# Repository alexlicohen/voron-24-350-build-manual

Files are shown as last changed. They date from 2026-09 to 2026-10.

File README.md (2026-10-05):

# Voron 2.4 R2 (LDO Rev D+, 350 mm) — build manual

**Live site:** <https://alexlicohen.github.io/voron-24-350-build-manual/> — one page per step, built from `docs/` on every push to `main`.

A Prusa-style, single-track build manual for an LDO Voron 2.4 R2 Rev D+ 350 kit, with every printed part produced on a Prusa Core One+. Numbered steps, fasteners per step, "what you should see" checks, and print batches interleaved with assembly so the printer never idles and no chapter waits on a part.

- `docs/manual/00-index.md` — start here: the interleaved print/build timeline, critical path, corrections log.
- `docs/manual/00-…14-*.md` — assembly chapters (frame → calibration), transcribed from the official Voron 2.4r2 manual with LDO Rev D/D+ deviations inline.
- `docs/manual/print/` — PrusaSlicer setup (quality-first overrides) and eleven print-batch chapters with per-plate packing lists.
- `docs/voron-print-plan.md`, `docs/voron-build-instructions-survey.md` — the research the chapters are built from.
- `slicer/` — the PrusaSlicer 2.9.6 config bundle and one committed project per plate.

The manual reads as **one page per step**, Prusa-style. `scripts/build_steps.py` runs as an mkdocs hook and regenerates `docs/manual/steps/` on every build — a chapter overview with a thumbnail grid, plus one page per `### Step NN.M` with prev/next, from the chapter markdown, which stays the single source. That directory is gitignored; the chapters are what you edit. Contract: [`docs/manual/CONVENTIONS.md` § Step pages](docs/manual/CONVENTIONS.md).

Optional bench tooling, not part of the manual: `scripts/ingest_photos.py` files a photo of a step from a drop folder (resize, EXIF strip) and `scripts/photo_wanted.py` lists steps with no illustration. Alex's 2026-09-06 ruling is that this is a manual to build from, not a record — the manual asks for no photos, and neither script is needed to build or read it.

## Slicer projects

`slicer/` holds a PrusaSlicer **2.9.6** project for each of the 22 plates (`slicer/plates/B01-P1.3mf`, 30 MB total), each one carrying its own arrangement on the 250 × 220 bed, its per-object brims and the complete print/filament/printer configuration — open one with **File → Open Project** and slice, without re-entering the thirty-odd Voron overrides by hand or guessing at a plate layout. The configuration is generated, not hand-written: `slicer/build_config.py` reads the system presets (`0.20mm STRUCTURAL @COREONE 0.4`, `Prusament ASA @COREONE HF0.4`, `Prusa CORE One HF0.4 nozzle`) out of the `PrusaResearch.ini` shipped with the installed slicer, resolves `inherits`, applies the override table from `docs/manual/print/00-slicer-setup.md`, and writes `slicer/OVERRIDES.md` mapping every key back to the doc line it came from. Every hour and gram quoted in the print plan and the batch chapters is read from the G-code these projects produce (`slicer/estimates.csv`), which is why they replaced the throughput model that preceded them: **157.0 h / 2092 g**, against the model's 134.3 h / 2248 g. Rebuild the lot with `python3 slicer/fetch_stls.py && python3 slicer/build_plates.py` — the STLs themselves are not committed (78 MB, re-fetchable from the commits pinned in `slicer/stl/MANIFEST.sha256`).

## Read it

```bash
python3 -m venv .venv && .venv/bin/pip install -r requirements.txt
./scripts/serve.sh        # prints the LAN URL; open it on a tablet at the bench
```

The rendered manual pages under `docs/manual/assets/manual-pages/` come from the official manual PDF, which is not committed (size). To regenerate:

```bash
curl -L -o docs/manual/assets/Voron2.4r2-manual.pdf \
  https://raw.githubusercontent.com/VoronDesign/Voron-2/de7e89d/Manual/Assembly_Manual_2.4r2.pdf
pdftoppm -png -r 110 docs/manual/assets/Voron2.4r2-manual.pdf docs/manual/assets/manual-pages/manual-p
```

The rendered Stealthburner manual pages under `docs/manual/assets/sb-pages/` come from the official Stealthburner manual PDF, also not committed (size). To regenerate:

```bash
curl -L -o docs/manual/assets/Voron-Stealthburner-manual.pdf \
  https://raw.githubusercontent.com/VoronDesign/Voron-Stealthburner/1bccf0543f40741243d81505c4ad5406eb822715/Manual/Assembly_Manual_SB.pdf
pdftoppm -png -r 110 docs/manual/assets/Voron-Stealthburner-manual.pdf docs/manual/assets/sb-pages/sb-p
# the SB manual has <100 pages, so pdftoppm 2-digit-pads by default — rename to the 3-digit sb-pNNN.png the chapters reference
cd docs/manual/assets/sb-pages && for f in sb-p-*.png; do n=$(echo "$f" | sed -E 's/sb-p-0*([0-9]+)\.png/\1/'); mv "$f" "$(printf sb-p%03d.png "$n")"; done && cd -
```

## Sources and drift

Every external URL cited in `docs/**/*.md` is inventoried in [`sources.yml`](sources.yml) — one row per source, with a title, a `kind`, and (for GitHub sources) the commit SHA of the default branch at the time it was last checked. Rebuild the inventory with `python3 scripts/sources_build.py`; re-check it with `python3 scripts/sources_verify.py --dry-run` (add no flag to also refresh `last_verified`/`sha` in place).

[`.github/workflows/drift.yml`](.github/workflows/drift.yml) runs weekly against the git repos this manual is most exposed to (`Voron-2`, `Voron-Documentation`, LDO's `Nitehawk-SB-V2` and `LDOVoron2`, `Voron-Stealthburner`, PrusaSlicer's settings repo) and opens or updates a single "Upstream drift" issue when any of them moves or a pinned URL stops resolving. It does not diff `docs.ldomotors.com` — that site is JS-rendered and would be all noise; LDO drift still surfaces through the corrections log and manual URL checks.

## Contributing

Found a step that doesn't match your kit? See [`CONTRIBUTING.md`](CONTRIBUTING.md) — corrections and questions both have issue templates, and PRs run through the same `mkdocs build --strict` + `scripts/lint_manual.py` checks as `main`.

## CI and deploy

`.github/workflows/check.yml` runs on every PR: `mkdocs build --strict` (with `validation.links.anchors: warn`, so a broken cross-reference anchor now fails the build, not just a missing file), the `hooks/callouts.py` self-test, and `scripts/lint_manual.py` (truncated callouts, dangling `Step NN.M` references, STLs printed in no batch, tables over 7 columns, and the per-step word budgets from `docs/manual/CONVENTIONS.md`). `.github/workflows/deploy.yml` runs on push to `main`: same strict build, then `mkdocs gh-deploy --force` — chosen over `actions/deploy-pages` because `gh-pages` already exists as a classic branch-based Pages source and this keeps that config unchanged.

## Attribution and licences

- Voron 2.4r2 assembly manual pages (rendered PNGs) and Stealthburner/gantry-squaring images: © VoronDesign, [GPL-3.0](https://github.com/VoronDesign/Voron-2/blob/Voron2.4/LICENSE). Page images are reproduced under that licence; the pinned source commit is `de7e89d`.
- Voron Stealthburner assembly manual pages (rendered PNGs, `docs/manual/assets/sb-pages/`): © VoronDesign, [GPL-3.0](https://github.com/VoronDesign/Voron-Stealthburner/blob/main/LICENSE). Reproduced under that licence; the pinned source commit is `1bccf054`.
- LDO Motors documentation images (docs.ldomotors.com) and MotorDynamicsLab repository images (LDOVoron2, Leviathan, Nitehawk-SB-V2) are reproduced with attribution for this non-commercial build manual; each mirrored file is listed in the folder's `SOURCES.txt` with its original URL. © LDO Motors. If LDO objects, open an issue and the images will be replaced with links.
- Per-part renders (`docs/manual/assets/parts/`), explanatory diagrams (`docs/manual/assets/diagrams/`) and CAD-derived step views (`docs/manual/assets/cad/`, from the GPL-3.0 Voron 2.4r2 STEP assembly at commit `de7e89d`) are generated by scripts in `scripts/`; regenerate with `python scripts/render_parts.py`, `python scripts/draw_diagrams.py`, and the pipeline described in `docs/manual/assets/cad/PILOT.md`.
- Klipper documentation excerpts are GPL-3.0.
- Everything else in this repository (chapter text, print plan, survey) is provided as-is for personal builds; no warranty. Steps marked `(verify on bench)` are counts or details no source states — confirm on your own kit.
- This repository's own content (chapter text, print plan, survey, diagrams, renders, scripts and the bench and add-on designs it generates) is licensed [CC BY-NC-SA 4.0](https://creativecommons.org/licenses/by-nc-sa/4.0/) (`LICENSE`). Third-party material listed above keeps its own licence: GPL-3.0 stays GPL-3.0 (Voron, Stealthburner, Klipper, the B11 duct remixes in `slicer/stl/bayducts/`, the Clicky-Clack images), and LDO's images remain © LDO Motors.
- `docs/manual/assets/` intentionally keeps the full rendered page range from each source PDF, including pages no chapter currently cites — that's deliberate (chapters are still being filled in against page references), not an oversight.

This manual is for one specific kit revision. If your kit differs (Rev C/D, different toolboard, different probe), the corrections log in the index tells you which steps to re-check.

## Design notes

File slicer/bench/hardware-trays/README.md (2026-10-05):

# Hardware trays (bench print)

Three ultra-light Gridfinity bins on one common footprint (5 × 5 units), each only as tall as its contents
need, that hold the LDO Voron 2.4 350 kit's fastener bags: one
compartment per hardware row of the kit BOM, two raised label lines (size; type and kit count) on a ledge
behind each row, and a scoop cove along each compartment's front wall. They sit on any Gridfinity baseplate
(Clickfinity included), and any of them stacks on any other. The bags are emptied into them on kit day,
[Ch 00 Step 00.12](../../../docs/manual/00-before-you-start.md#step-0012-empty-the-fastener-bags-into-the-hardware-trays).
A bench print: on no plate, in no batch, run total or spool ledger
([print/README § Bench prints](../../../docs/manual/print/README.md#bench-prints-outside-the-plates)).

| Tray | Holds |
|---|---|
| A | M2 and M3 screws: SHCS by length, BHCS, FHCS, wafer, captive, M2 self-tappers, M3 set screws |
| B | M4 and M5 screws (M5 SHCS, M4 and M5 BHCS, M4 set screws) and the hammer-head T-nuts |
| C | the small parts (hex nuts, heat-set inserts, washers, spacers, lock washers, knurled nuts, magnets) and the roll-in T-nuts, in a low bin |

The kit's hand tools (hex keys, the 2 mm drill bit, the slot screwdriver, the brass insert tip) are not
stored in the trays. Renders (blue = the layers above the label ledges, i.e. the colour-change layers):
`renders/tray-{A,B,C}-top.png` and `renders/tray-{A,B,C}-34.png`.

## Files

| File | What |
|---|---|
| `gen_trays.py` | the only generator (CadQuery, `venv-cq`; no other dependency) |
| `tray-{A,B,C}.stl` | print-ready meshes, as oriented |
| `tray-{A,B,C}.3mf` | PrusaSlicer 2.9.6 projects, one tray per bed, config embedded |
| `renders/*.png` | top and 3/4 views of each tray, and a Y–Z section (`-section.png`) |

## Regenerate

```sh
venv-cq/bin/python slicer/bench/hardware-trays/gen_trays.py            # STLs, renders, 3MFs, slice, README blocks
venv-cq/bin/python slicer/bench/hardware-trays/gen_trays.py --plan     # groupings and fill table only, writes nothing
venv-cq/bin/python slicer/bench/hardware-trays/gen_trays.py --compare 3  # build and slice the 3 best groupings, print h and g
venv-cq/bin/python slicer/bench/hardware-trays/gen_trays.py --lever-study  # slice with the plastic levers added one by one
venv-cq/bin/python slicer/bench/hardware-trays/gen_trays.py --levers none  # the plain (solid-base, 2.6 mm wall) bins
venv-cq/bin/python slicer/bench/hardware-trays/gen_trays.py --no-slice
venv-cq/bin/python slicer/bench/hardware-trays/gen_trays.py --holes magnet   # or screw; default none
venv-cq/bin/python slicer/bench/hardware-trays/gen_trays.py --validate REF.stl   # profile check, below
```

Everything is read from the data: the rows of box *Fasteners, Tools & Misc* in `scripts/data/ldo-350-bom.yml`
(re-pinned to the batch sheet on kit day, Step 00.2) and the `tool` roles in
`scripts/data/hardware-ownership.yml`. Re-run after a re-pin; the grid, the split, the compartment sizes and
the labels follow the counts. The script stops on a BOM row it has no rule for (`classify()`), on any
compartment over 70 % fill or under the finger floor, on a slicer stability warning, and if no split fits
six trays. The STLs and renders are byte-identical between runs. About 5 minutes.

Not in a compartment: the PTFE tube, the zip ties, the two aluminium handles and the hand tools. The Motion
box's loose parts (F695 and 625 bearings, pulleys, GT2 idlers, 5×60 shafts, the nozzle-probe shaft, MR85s,
the IDGA gear set, the Bowden coupler) stay sealed in their own kit bags: they are sealed precision parts
that only pick up grit in an open tray, each bag already holds one part type with its name on it, and they
are opened at a few known drive and toolhead steps, not drawn on every session like the screws.

## Fill check

Every compartment is sized so its loose contents fill at most **70 %** of its usable volume, leaving room to
scoop, and the script fails if one does not. Per hardware row:

- **Envelope:** the bounding shape of one piece: a cylinder of the head diameter over the overall length
  for screws (head height + length; length only for FHCS), a cylinder across the corners for hex nuts,
  diameter × thickness for washers, spacers, inserts and magnets, a box for T-nuts. Shank diameter is the
  nominal thread.
- **Bulk volume** = count × envelope ÷ φ, the random-loose packing fraction of that envelope:
  - screws: 0.55 at envelope length/diameter ≤ 2 down to 0.45 at ≥ 8, linear between. Random packings of
    cylinders loosen as they get longer, and the bounding cylinder already pads the shank out to the head
    diameter.
  - set screws, inserts, washers, spacers, T-nuts: 0.55 (short, blocky or flat pieces that interlock or
    shingle).
  - hex nuts, knurled nuts: 0.58; magnets: 0.60 (they chain and stack).
- **Usable volume** = compartment floor area × depth from the floor to the rim (the divider tops), less the
  rounded vertical corners (R2.9), the scoop cove (always R12: compartments are at least 18 mm long and 21 mm deep, so it never shrinks), and
  on a side against the outer wall the 1.74 × 1.74 mm 45° sliver of the lip support.
- **Fill** = bulk ÷ usable. Compartments are sized from the 70 % rule, with a floor of 25 mm wide × 18 mm long
  so a finger fits, and wider where the label (or a screw lying along X) needs it; spare space is shared out
  in proportion.

Sources for the piece dimensions (column *source* in the generated table):

- ISO 4762 / 7380 / 10642 / 4032 / 7089 / 14583 / 4026: the dimension tables in
  [gumyr/bd_warehouse @eed2da1](https://github.com/gumyr/bd_warehouse/tree/eed2da118da99007ad2d3904466ac0b24964f84d/src/bd_warehouse/data)
  (`socket_head_cap_`, `button_head_`, `countersunk_head_`, `hex_nut_`, `plain_washer_`, `pan_head_parameters.csv`).
  Maxima where the table gives them (SHCS M3 head 5.68, not the nominal 5.5), so the envelopes err large.
- CAD: bounding boxes in the Voron 2.4r2 assembly STEP (VoronDesign/Voron-2) of the part the Voron design
  itself models for that BOM line: the roll-in T-nuts ("2020 Drop-in T-nut", 12.5–13.0 × 7.7 × 4.3), the M3
  hammer-head (10.92 × 9.14 × 4.85), the M5 1 mm shim (10 × 1), the insert's knurl (5.35), the DIN 466-B
  knurled nut (14.08 × 8), the magnet, the M2×10 self-tapper (4.0 × 11.6).
- NAME: the size in the LDO BOM text (M3x5x4 insert, 6x3 magnet, the 1 mm washer).
- EST, no drawing found: the M3×25 wafer head (Ø8 × 1.5), the M3×6 captive screw (as an ISO 4762 head),
  the M5 hammer-head T-nut (as the M3 one, 11 × 9.2 × 5), the twisted M5 split lock washer (9.2 × 2.4).

**Validation of the packing method: none.** No published loose-bulk figure for small screws was found (a
search for loose bulk density of M3 screws or small fasteners turned up only solid density and per-piece
masses), so the φ values are judgement within the brief's ranges, not measured. The implied solid fraction
of the loose pile (count × solid volume ÷ bulk, column *solid/bulk* below) runs from about 0.1 for long
screws to about 0.5 for washers; loose screws in a tray likely lie flatter than that, so the method errs
roomy for long screws. Kit day is the cheap calibration: tip the 283 M3×8 into their compartment and read the
fill against the table.

## Gridfinity

Implemented in CadQuery from the published spec, no Gridfinity library:
[gridfinity.xyz/specification](https://gridfinity.xyz/specification/) ("Gridfinity Design Reference v5",
willtree8) and the constants in
[kennetek/gridfinity-rebuilt-openscad `src/core/standard.scad` @910e22d](https://github.com/kennetek/gridfinity-rebuilt-openscad/blob/910e22d8607fd7f5f51ad5e5cbc5287a76810bfd/src/core/standard.scad).

| Feature | Value used |
|---|---|
| Grid | 42 mm pitch; bin outer 42 n − 0.5 (5 units: 209.5 mm); corner radius 3.75 (Ø7.5) |
| Base, per unit | from the bottom: 0.8 at 45°, 1.8 vertical, 2.15 at 45° (4.75 high); bottom 35.6 square r0.8, top 41.5 r3.75 |
| Height | 7 mm units; bin height 7 u includes the 7 mm base (profile + bridge) and excludes the lip (6U = 42 mm) |
| Stacking lip | from its inner tip at the bin height: 0.7 at 45°, 1.8 vertical, 1.9 at 45° (2.6 deep, 4.4 high) |
| Interior | floor at 5.8 (a floor plate on top of hollow feet, below); dividers and labels stop 1.2 below the bin height (rebuilt's lip support height), so a bin stacked on top never touches them |
| Holes (option) | magnet Ø6.5 × 2.4, or M3 Ø3 × 6, 8 mm in from each side of every unit; none by default (Clickfinity baseplates hold bins without magnets) |

Deliberate differences: the lip's knife-edge top is cut back to a 0.3 mm flat, so the bin is 0.3 mm under
the spec's height (rebuilt rounds the same edge with r0.6 instead); the inside is ultra-light (§ Ultra-light
below). The outside, feet and lip included, is unchanged, and the validation below is of these bins.

**Validation** (`--validate`, section through the unit centre, a plain 1 × 1 × 6U bin from this script
against a reference STL, both centred and bottom-aligned):

| Reference | Base outside | Wall outside | Lip inside |
|---|---|---|---|
| Gridfinity Refined, `Bin Handle w Lip.stl` ([Printables 413761](https://www.printables.com/model/413761), CC BY-SA) | 0.012 mm | 0.000 mm | 0.012 mm |
| Gridfinity Lite, `gridfinity-lite-1x1x6.stl` ([Printables 265271](https://www.printables.com/model/265271), CC BY) | 0.250 mm | 0.001 mm | 0.250 mm |

The Refined bin matches the spec to the mesh tolerance. The Lite bin's base and lip are both 0.25 mm per
side inside the spec numbers everywhere (bottom 35.2, not 35.6; lip 2.85 deep, not 2.6): a uniform offset,
the 0.25 clearance an older gridfinity-rebuilt applied to the profile itself. Either fits a standard
baseplate; these trays follow the current spec numbers.

## Print

Core One+, satin sheet (the PLA sheet, per `docs/manual/print/00-slicer-setup.md` § Print sheet), any PLA, door open. Each project carries its config, flattened from the
PrusaSlicer 2.9.6 system presets `0.20mm BALANCED @COREONE HF0.4` + `Prusament PLA @COREONE HF0.4` +
`Prusa CORE One HF0.4 nozzle` (`slicer/resolve_preset.py`), with this repo's printer-wide lines: the vendored
cold start (`slicer/coreone-cold-start.gcode`) and `M106 P3 S160` / `M106 P3 R` in the filament start/end
G-code (AFS bypass flaps, as `slicer/bay-ducts-petg.ini` does for PETG). Supports off. Ultra-light settings:
2 perimeters, 3 top and 3 bottom layers (minimum-thickness rules off, so it is 3 layers), 10 % infill; nothing
else is overridden (0.2 mm layers, 0.45 mm lines). The base's 45° steps print without support.

**Two-colour labels (optional):** the labels, the top 0.6 mm of the dividers and the stacking lip are
everything above the label ledges. In PrusaSlicer's layer slider, add a colour change (M600) at the tray's
*colour change Z* in the slice table below (the first layer above the ledges), then load the label colour
when the printer asks.

**No lids.** A bin stacked on a tray of the same footprint closes it (its base sits in the stacking lip), and
the bins sit on any Gridfinity baseplate. Which trays stack, and which fit the optional closed carry box,
[Gridfinity 5×4 rugged case, Voron Edition](https://www.printables.com/model/857097) (Akio, CC BY-NC-SA; a
5 × 4 grid of 6U bins), is worked out in the generated block below.

**Grouping.** The generator groups whole hardware families (M2/M3 screws, M4/M5 screws, roll-in T-nuts,
hammer-head T-nuts, small parts) into at most three trays on one common footprint, each tray at its lowest
height: fewest trays, then the fewest bin units (Σ n·m·U, a plastic proxy); groupings that tie on bin units
are sliced and the lightest wins. No tray is lower than **`MIN_U` = 4** (Alex: parts must not spill when a
tray tilts), and every piece lying flat stays at least 2 mm below the rim. Only 5 × 5 holds the M2/M3 screws,
so 5 × 5 is the common footprint. With `MIN_U` = 4 the best three groupings, all sliced (`--compare 3`,
ultra-light, 2026-10-05):

| Grouping (A / B / C) | Bin units | Time | PLA |
|---|---:|---|---:|
| M2/M3 6U / M4/M5 + hammer-head T-nuts 5U / roll-in T-nuts + small parts 4U (**built**) | 375 | 18.6 h | 652 g |
| M2/M3 6U / M4/M5 5U / all T-nuts + small parts 4U | 375 | 18.9 h | 663 g |
| M2/M3 6U / M4/M5 + roll-in T-nuts 6U / hammer-head T-nuts + small parts 4U | 400 | 19.2 h | 676 g |

The 4U floor costs 16 g and 0.4 h against the 3U small-parts tray it replaces (636 g, 18.2 h). The extra depth
moves nothing: the first two tie on bin units, so the slice decides, and the grouping already built is the
lighter by 11 g. Putting all the T-nuts with the M4/M5 screws still does not fit a 6U bin.

Every compartment has the full R12 scoop cove on its front wall, solid. `renders/tray-{A,B,C}-section.png`
are Y–Z sections through each tray at a third of its width, drawn from the STL, showing the coves, the label
ledges, the hollow feet and the lip.

## Ultra-light

Ideas from **HuMa**, *Gridfinity Ultra Light Bins* ([Printables 627719](https://www.printables.com/model/627719),
CC BY-NC-SA: 37 % less filament than a standard bin, a 3 × 4 × 6 bin 62 g instead of 98 g at 2 walls, 3 top
and bottom layers, 10 % infill). Ideas only; no geometry is used. Each lever, sliced with the others before it
(`--lever-study`, 2026-10-05, before `MIN_U` = 4 and the fixed R12 cove; grouping and heights re-chosen at
each step):

| Lever | A | B | C | All | Change | Kept |
|---|---:|---:|---:|---:|---:|---|
| none (the bins as approved: solid 7 mm base, 2.6 mm wall, 1.8 mm dividers) | 359 g 6U | 329 g 6U | 227 g 3U | 915 g, 23.8 h | | |
| `settings`: 2 perimeters, 3 top / 3 bottom, 10 % infill | 306 | 278 | 187 | 771 g, 20.3 h | −144 g | yes |
| `thin`: outer wall and dividers 0.86 mm (exactly 2 perimeters); lip on a 45° support | 271 | 214 (5U) | 207 (4U) | 692 g, 18.8 h | −79 g | yes |
| `ledges`: hollow under each label ledge, 45° roof | 269 | 219 | 219 | 707 g, 20.2 h | +15 g | **no** |
| `coves`: hollow inside each scoop cove, 45° roof | 274 | 225 | 225 | 724 g, 20.9 h | +17 g | **no** |
| `base`: hollow feet under a floor plate (with the two above still on) | 259 | 212 | 184 (3U) | 655 g, 19.8 h | −69 g | yes |
| **built**: `settings` + `thin` + `base` | 262 | 207 | 167 | **636 g, 18.2 h** | **−279 g (−30 %)** | |

- **Settings** pays most: the trays are almost all wall, so cutting top layers and infill takes plastic off
  every floor and ledge. All three trays slice with **0 gap-fill extrusions**.
- **Thin walls**: a 0.45 mm line at 0.2 mm layers spaces at 0.407, so two perimeters make a 0.86 mm wall
  with nothing between them. With a wall thinner than the 2.6 mm lip, the lip's inner tip sits on a 45° ring
  (from the wall face 1.74 mm below the rim up to the tip line at the rim, then straight up to the bin
  height): the same support gridfinity-rebuilt uses, and the load path for a stacked bin. The lip itself
  is left as the spec draws it: its 6.8 mm² section is at most ~5 g a tray, and it carries the stack. The
  tray name on the front face is dropped: a cut into a 0.86 mm wall leaves less than two perimeters.
- **Hollow ledges and coves cost plastic.** At 10 % infill a void inside a 13 mm ledge or a cove adds two
  perimeters round it on every layer, more than the sparse infill it replaces, and more print time. Both are
  implemented (`--levers settings,thin,ledges,coves,base`) and off.
- **Hollow base**: each foot is a shell, 0.86 mm walls following the foot profile and a 3-layer (0.6 mm)
  pocket floor, closed on top by a 1.05 mm floor plate at the base top (z 4.75–5.8); the compartment floor
  is flat at 5.8, 1.2 mm lower than before. The call: a **flat floor over closed feet**, not floors dipping
  into the feet as HuMa's bins do. Dipped floors would leave a 5 mm ridge every 42 mm across every
  compartment, wells with 45° sides where washers, magnets and set screws collect, and V-notches where a
  divider crosses a well; the coves would hang over the wells. The flat floor costs a 40 mm bridge over
  each foot pocket (PrusaSlicer's stability check lists it with the base grooves as "Long bridging
  extrusions"; no supports) and some of the plastic dipping would save. No tray drops a height unit from
  the lower floor alone: A still needs 6U, and `MIN_U` keeps C at 4U. Holes (`--holes`) need
  solid feet, so the option turns the hollow base off.

**Strength.** Tray A full is about 0.5 kg of steel.
- *Lifted by one end*: the tray is a box 209.5 × 209.5 × 42 mm with 0.86 mm walls. Every 25–80 mm a 0.86 mm
  divider is fused to the outer wall, and every row ends in a solid 13.2 mm label ledge running wall to wall
  (ribs). The floor is a 1.05 mm plate on 25 foot shells. The worst case, held at one edge with the steel
  spread evenly, puts about 0.5 N·m of bending on that section: well under 1 MPa in PLA, which yields near
  50 MPa. The lip is solid, so it is a sound place to grip.
- *Two full trays stacked*: about 5 N rests on the lower tray's lip ring, about 820 mm long, carried by the
  45° support into the walls: a few kPa.
- *Floor*: a 1.05 mm plate spans each 40 mm foot pocket, edges fixed, carrying a fraction of a newton per pocket.
- Every wall and divider is at least 2 perimeters, the floors at least 3 layers. Nothing here is close to
  a limit; the limit in use is a drop, not a load.

<!-- BEGIN generated:layout -->
Generated from `scripts/data/ldo-350-bom.yml` (box *Fasteners, Tools & Misc*, fetched 2026-09-24). Each tray is sized on its own: the smallest footprint, then the lowest height, that holds its group at ≤ 70% fill with the finger floor.

3 groupings of whole families fit ≤ 3 trays on one common footprint, each tray at its lowest height. Best five by bin units (Σ n·m·U, the plastic proxy):

1. 3 trays, 375 bin units: M2/M3 screws 5×5×6U | M4/M5 screws 5×5×5U | roll-in T-nuts + hammer-head T-nuts + small parts 5×5×4U
2. 3 trays, 375 bin units: M2/M3 screws 5×5×6U | M4/M5 screws + hammer-head T-nuts 5×5×5U | roll-in T-nuts + small parts 5×5×4U ← chosen
3. 3 trays, 400 bin units: M2/M3 screws 5×5×6U | M4/M5 screws + roll-in T-nuts 5×5×6U | hammer-head T-nuts + small parts 5×5×4U

2 groupings tie at 375 bin units; sliced: 1. 663 g, 18.9 h; 2. 652 g, 18.6 h. Chosen: 2, the lightest.

Usable depth (floor to rim) by height: 4U 21.0 mm, 5U 28.0 mm, 6U 35.0 mm.

| tray | bin | thickest piece lying flat (mm) | lowest height the fill allows |
|---|---|---:|---|
| A | 5 × 5 × 6U | 8 | 6U |
| B | 5 × 5 × 5U | 9.5 | 5U |
| C | 5 × 5 × 4U | 8 | 4U |

Stacking: a bin rests on another bin's stacking lip only if both have the same footprint (the lip runs round the rim, so a smaller bin's feet would drop inside). A, B and C share a footprint: any of them stacks on any other.
None of the trays fits the 5 × 4 rugged case.

**Tray A — M2 · M3 SCREWS:** Gridfinity 5 × 5 × 6U (209.5 × 209.5 × 42 mm + lip), 17 compartments in 4 rows (row 1 is the front); fullest M3×40 SHCS at 67%.

| row | label | count | piece envelope mm | φ | bulk cm³ | size mm | usable cm³ | fill |
|---:|---|---:|---|---:|---:|---|---:|---:|
| 1 | M3×8 · SHCS 283 | 283 | cyl 5.68 × 11 | 0.55 | 143.4 | 109 × 59 × 35.0 | 221.2 | 65% |
| 1 | M3×12 · SHCS 50 | 50 | cyl 5.68 × 15 | 0.54 | 35.2 | 31 × 59 × 35.0 | 62.9 | 56% |
| 1 | M3×16 · SHCS 30 | 30 | cyl 5.68 × 19 | 0.53 | 27.4 | 31 × 59 × 35.0 | 63.4 | 43% |
| 1 | M3×20 · SHCS 40 | 40 | cyl 5.68 × 23 | 0.52 | 45.2 | 34 × 59 × 35.0 | 69.6 | 65% |
| 2 | M3×25 · SHCS 12 | 12 | cyl 5.68 × 28 | 0.50 | 17.0 | 38 × 29 × 35.0 | 36.8 | 46% |
| 2 | M3×30 · SHCS 44 | 44 | cyl 5.68 × 33 | 0.49 | 75.6 | 119 × 29 × 35.0 | 115.4 | 66% |
| 2 | M3×35 · SHCS 6 | 6 | cyl 5.68 × 38 | 0.47 | 12.2 | 49 × 29 × 35.0 | 47.2 | 26% |
| 3 | M3×40 · SHCS 34 | 34 | cyl 5.68 × 43 | 0.46 | 81.0 | 78 × 45 × 35.0 | 120.8 | 67% |
| 3 | M3×50 · SHCS 4 | 4 | cyl 5.68 × 53 | 0.45 | 11.9 | 62 × 45 × 35.0 | 95.7 | 12% |
| 3 | M3×6 · BHCS 14 | 14 | cyl 5.7 × 7.65 | 0.55 | 5.0 | 30 × 45 × 35.0 | 46.3 | 11% |
| 3 | M3×25 · BHCS 6 | 6 | cyl 5.7 × 26.65 | 0.51 | 8.1 | 36 × 45 × 35.0 | 55.6 | 15% |
| 4 | M3×6 · FHCS 42 | 42 | cyl 6 × 6 | 0.55 | 13.0 | 32 × 20 × 35.0 | 20.9 | 62% |
| 4 | M3×10 · FHCS 8 | 8 | cyl 6 × 10 | 0.55 | 4.1 | 31 × 20 × 35.0 | 20.4 | 20% |
| 4 | M3×25 · WAFER 3 | 3 | cyl 8 × 26.5 | 0.53 | 7.6 | 35 × 20 × 35.0 | 22.9 | 33% |
| 4 | M3×6 · CAPTIVE 2 | 2 | cyl 5.68 × 9 | 0.55 | 0.8 | 36 × 20 × 35.0 | 24.0 | 3% |
| 4 | M2×10 · SELF-TAP 43 | 43 | cyl 4 × 11.6 | 0.54 | 11.7 | 42 × 20 × 35.0 | 27.9 | 42% |
| 4 | M3×2 · SET 5 | 5 | cyl 3 × 2 | 0.55 | 0.1 | 28 × 20 × 35.0 | 18.8 | 1% |

**Tray B — M4 · M5 SCREWS · T-NUTS:** Gridfinity 5 × 5 × 5U (209.5 × 209.5 × 35 mm + lip), 10 compartments in 3 rows (row 1 is the front); fullest M5×40 SHCS at 69%.

| row | label | count | piece envelope mm | φ | bulk cm³ | size mm | usable cm³ | fill |
|---:|---|---:|---|---:|---:|---|---:|---:|
| 1 | M5×40 · SHCS 26 | 26 | cyl 8.72 × 45 | 0.50 | 140.5 | 154 × 48 × 28.0 | 203.3 | 69% |
| 1 | M4×6 · BHCS 8 | 8 | cyl 7.6 × 8.2 | 0.55 | 5.4 | 25 × 48 × 28.0 | 33.4 | 16% |
| 1 | M5×6 · BHCS 1 | 1 | cyl 9.5 × 8.75 | 0.55 | 1.1 | 27 × 48 × 28.0 | 35.7 | 3% |
| 2 | M5×10 · BHCS 54 | 54 | cyl 9.5 × 12.75 | 0.55 | 88.7 | 51 × 92 × 28.0 | 128.7 | 69% |
| 2 | M5×14 · BHCS 4 | 4 | cyl 9.5 × 16.75 | 0.55 | 8.6 | 29 × 92 × 28.0 | 74.6 | 12% |
| 2 | M5×16 · BHCS 43 | 43 | cyl 9.5 × 18.75 | 0.55 | 103.9 | 59 × 92 × 28.0 | 150.9 | 69% |
| 2 | M5×30 · BHCS 26 | 26 | cyl 9.5 × 32.75 | 0.53 | 114.8 | 66 × 92 × 28.0 | 166.5 | 69% |
| 3 | M4×4 · SET 32 | 32 | cyl 4 × 4 | 0.55 | 2.9 | 27 × 26 × 28.0 | 18.7 | 16% |
| 3 | M3 T-NUT · HAMMER 75 | 75 | box 10.92 × 9.14 × 4.85 | 0.55 | 66.0 | 137 × 26 × 28.0 | 95.5 | 69% |
| 3 | M5 T-NUT · HAMMER 16 | 16 | box 11 × 9.2 × 5 | 0.55 | 14.7 | 42 × 26 × 28.0 | 28.9 | 51% |

**Tray C — NUTS · INSERTS · WASHERS · MAGNETS · T-NUTS:** Gridfinity 5 × 5 × 4U (209.5 × 209.5 × 28 mm + lip), 11 compartments in 3 rows (row 1 is the front); fullest M3 INSERT HEAT-SET at 58%.

| row | label | count | piece envelope mm | φ | bulk cm³ | size mm | usable cm³ | fill |
|---:|---|---:|---|---:|---:|---|---:|---:|
| 1 | M3 NUT · HEX 14 | 14 | cyl 6.35 × 2.4 | 0.58 | 1.8 | 41 × 35 × 21.0 | 29.0 | 6% |
| 1 | M5 NUT · HEX 30 | 30 | cyl 9.24 × 4.7 | 0.58 | 16.3 | 40 × 35 × 21.0 | 28.2 | 58% |
| 1 | M3 INSERT · HEAT-SET 153 | 153 | cyl 5.35 × 4 | 0.55 | 25.0 | 62 × 35 × 21.0 | 43.3 | 58% |
| 1 | M3 WASHER · 6 | 6 | cyl 7 × 0.55 | 0.55 | 0.2 | 62 × 35 × 21.0 | 43.6 | 1% |
| 2 | M5 WASHER · 1 mm · 9 | 9 | cyl 10 × 1 | 0.55 | 1.3 | 56 × 25 × 21.0 | 27.7 | 5% |
| 2 | M5 SPACER · 1 mm · 46 | 46 | cyl 10 × 1 | 0.55 | 6.6 | 50 × 25 × 21.0 | 24.9 | 26% |
| 2 | M5 LOCK · WASHER 2 | 2 | cyl 9.2 × 2.4 | 0.55 | 0.6 | 40 × 25 × 21.0 | 20.0 | 3% |
| 2 | M4 KNURLED · NUT 4 | 4 | cyl 14.08 × 8 | 0.58 | 8.6 | 59 × 25 × 21.0 | 29.5 | 29% |
| 3 | 6×3 MAGNET · 16 | 16 | cyl 6 × 3 | 0.60 | 2.3 | 70 × 106 × 21.0 | 152.9 | 1% |
| 3 | M3 T-NUT · ROLL-IN 135 | 135 | box 12.5 × 7.7 × 4.3 | 0.55 | 101.6 | 84 × 106 × 21.0 | 184.8 | 55% |
| 3 | M5 T-NUT · ROLL-IN 80 | 80 | box 13 × 7.7 × 4.3 | 0.55 | 62.6 | 52 × 106 × 21.0 | 113.8 | 55% |

Piece data and sources:

| BOM item | solid mm³ | envelope mm³ | solid/bulk | source |
|---|---:|---:|---:|---|
| Machine Screw, SHCS, M3x8 | 133 | 279 | 0.26 | ISO 4762 |
| Machine Screw, SHCS, M3x12 | 161 | 380 | 0.23 | ISO 4762 |
| Machine Screw, SHCS, M3x16 | 189 | 481 | 0.21 | ISO 4762 |
| Machine Screw, SHCS, M3x20 | 217 | 583 | 0.19 | ISO 4762 |
| Machine Screw, SHCS, M3x25 | 253 | 709 | 0.18 | ISO 4762 |
| Machine Screw, SHCS, M3x30 | 288 | 836 | 0.17 | ISO 4762 |
| Machine Screw, SHCS, M3x35 | 323 | 963 | 0.16 | ISO 4762 |
| Machine Screw, SHCS, M3x40 | 359 | 1090 | 0.15 | ISO 4762 |
| Machine Screw, SHCS, M3x50 | 429 | 1343 | 0.14 | ISO 4762 |
| Machine Screw, BHCS, M3x6 | 85 | 195 | 0.24 | ISO 7380 |
| Machine Screw, BHCS, M3x25 | 219 | 680 | 0.16 | ISO 7380 |
| Machine Screw, FHCS, M3x6 | 58 | 170 | 0.19 | ISO 10642 |
| Machine Screw, FHCS, M3x10 | 87 | 283 | 0.17 | ISO 10642 |
| Machine Screw, Wafer head, M3x25 | 252 | 1332 | 0.10 | EST (wafer head 8 × 1.5) |
| Machine Screw, Captive, M3x6 | 118 | 228 | 0.29 | EST (as ISO 4762 head) |
| Self-tapping Screw, M2x10 | 52 | 146 | 0.19 | ISO 14583 pan head; CAD 4.0 × 11.6 |
| Set Screw, M3x2, Pre-applied Threadlocker | 14 | 14 | 0.55 | ISO 4026 (d × L) |
| Machine Screw, SHCS, M5x40 | 1084 | 2687 | 0.20 | ISO 4762 |
| Machine Screw, BHCS, M4x6 | 175 | 372 | 0.26 | ISO 7380 |
| Machine Screw, BHCS, M5x6 | 313 | 620 | 0.28 | ISO 7380 |
| Machine Screw, BHCS, M5x10 | 391 | 904 | 0.24 | ISO 7380 |
| Machine Screw, BHCS, M5x14 | 470 | 1187 | 0.22 | ISO 7380 |
| Machine Screw, BHCS, M5x16 | 509 | 1329 | 0.21 | ISO 7380 |
| Machine Screw, BHCS, M5x30 | 784 | 2321 | 0.18 | ISO 7380 |
| Set Screw, M4x4, Pre-applied Threadlocker | 50 | 50 | 0.55 | ISO 4026 (d × L) |
| T-nut, Hammer Head, 2020, M3 | 185 | 484 | 0.21 | CAD |
| T-nut, Hammer Head, 2020, M5 | 190 | 506 | 0.21 | EST |
| Hexnut, M3 | 46 | 76 | 0.35 | ISO 4032 s, m |
| Hexnut, M5 | 168 | 315 | 0.31 | ISO 4032 s, m |
| Heatset Insert, Brass, M3x5x4 | 62 | 90 | 0.38 | NAME; CAD knurl 5.35 |
| Washer, M3 | 17 | 21 | 0.45 | ISO 7089 |
| Washer, M5, 1mm | 59 | 79 | 0.41 | ISO 7089; NAME thickness |
| Precision Spacer, M5, 1mm | 59 | 79 | 0.41 | CAD (M5 1mm Shim 10 × 1) |
| Locking Washer, M5 | 56 | 160 | 0.19 | EST (DIN 127 split, twisted) |
| Knurled Nut, M4 | 747 | 1246 | 0.35 | CAD (DIN 466-B) |
| 6x3mm Neodymium Magnet | 85 | 85 | 0.60 | NAME; CAD |
| T-nut, Roll-in, 2020, M3 | 286 | 414 | 0.38 | CAD |
| T-nut, Roll-in, 2020, M5 | 272 | 430 | 0.35 | CAD |

Not in a compartment: Teflon Tube (4mm OD 3mm ID) - 1.2m; Zip Ties, 3x150mm; Brass Heatset Insert tool (for M3 Brass Inserts); Drill bit, 2mm; Hex Wrench, 1.5mm; Hex Wrench, 2mm; Hex Wrench, 2.5mm; Hex Wrench, 3mm; Hex Wrench, 4mm; Slot head screwdriver, 2.5mm; Aluminium Handle.
<!-- END generated:layout -->

<!-- BEGIN generated:slice -->
| file | bin | time | g PLA | colour change Z | extents on the bed, mm | supports |
|---|---|---|---:|---:|---|---|
| `tray-A.3mf` | 5 × 5 × 6U | 7h 27m 41s | 262 | 40.40 | X 20.4–229.6, Y 5.4–214.6, Z ≤ 46.00 | none |
| `tray-B.3mf` | 5 × 5 × 5U | 5h 50m 21s | 208 | 33.40 | X 20.4–229.6, Y 5.4–214.6, Z ≤ 39.00 | none |
| `tray-C.3mf` | 5 × 5 × 4U | 5h 16m 33s | 182 | 26.40 | X 20.4–229.6, Y 5.4–214.6, Z ≤ 32.00 | none |

All trays: **18.6 h, 652 g**. PrusaSlicer 2.9.6 CLI estimates, one tray per bed, not GUI-arranged; 2 perimeters, 3 top / 3 bottom layers, 10% infill; 0 gap-fill extrusions; slicer stability notes: Long bridging extrusions (the base grooves and the hollow feet's 40 mm roofs, expected). The colour-change Z is the first label layer, checked against each G-code.
<!-- END generated:slice -->

## Credit and licence

Inspired by **r0bdawg11**, *INDX Upgrade Hardware Organizer*, <https://www.printables.com/model/1794124>
(CC BY): one flat tray, a compartment per hardware type, raised labels, a scoop fillet. Inspiration only;
no geometry is copied. The ultra-light construction takes its ideas from **HuMa**, *Gridfinity Ultra Light
Bins* (Printables 627719, CC BY-NC-SA); ideas only, no geometry used. The Gridfinity system is **Zack Freedman**'s; the base and lip here are built from
the published spec numbers, not from any Gridfinity model file.

Licence: **CC BY-NC-SA 4.0** (<https://creativecommons.org/licenses/by-nc-sa/4.0/>), the same as the rest of
this repository's own content (root `LICENSE`), which also matches what the Gridfinity design reference asks of
derived projects.

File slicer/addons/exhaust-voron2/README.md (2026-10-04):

# Chamber exhaust housing — add-on (Ch 14 Part H)

Optional. On no plate, in no batch (B00–B11), in no run total. **Printed only after Ch 14 Step 14.25 has
checked the back of the real machine** (stock notch, free depth behind it, extrusion slot, lead route,
spare jumper); never ahead of kit day.

## Licence and credit

**GPL-3.0** (<https://github.com/VoronDesign/Voron-2/blob/a192410/LICENSE>). The parts are the Voron Design
team's stock Voron 2.4r2 exhaust filter, *unchanged*: `VoronDesign/Voron-2` at
`a192410e27ea345644ae5c4b29b4c9c40cbe1a73` (branch `Voron2.4`), folder `STLs/Exhaust_Filter/`. Nothing is
remixed, so nothing is committed here; the files are fetched like every other stock part.

## Files

`python3 slicer/fetch_stls.py` downloads them to `slicer/stl/voron2/STLs/Exhaust_Filter/` (gitignored).
`slicer/plates.py` `ADDONS` lists them and `slicer/stl/MANIFEST.sha256` pins their hashes, so
`python3 slicer/fetch_stls.py --verify` fails if one changes. `sources.yml` pins the Voron-2 repo commit;
`python3 scripts/sources_verify.py --git-only` reports when it moves.

| File | Qty | Colour | Job |
|---|---:|---|---|
| `exhaust_filter_housing.stl` | 1 | Black | 1 |
| `[a]_exhaust_fan_grill.stl` | 1 | Blue | 2 |
| `[a]_filter_access_cover.stl` | 1 | Blue | 2 |
| `[a]_exhaust_filter_mount_x2.stl` | 2 | Blue | 2 |
| `exhaust_filter_grill.stl` | — | — | already printed in B09-P3 and fitted at Ch 11 Step 11.54; Part H reuses it |

## Print

Two jobs on the Core One+, smooth sheet, as oriented, **no supports**, Voron spec (4 walls, 5 top/bottom,
40 % grid, 0.2 mm):

| Job | Profile | PrusaSlicer 2.9.6 CLI estimate |
|---|---|---|
| 1 — housing | `slicer/voron-coreone-asa.ini`, Galaxy Black ASA | 66.0 g, 5 h 03 m |
| 2 — fan grill, access cover, 2 mounts | `slicer/voron-accent-blue.ini`, blue accent ASA | 34.6 g, 2 h 04 m |

Estimates were sliced with the parts laid side by side, not GUI-arranged (2026-10-03). All five
pieces go in bin `14-exhaust` (`slicer/bins.py` `ADDON_PARTS`); `exhaust_filter_grill` stays in `11-nevermore`,
where B09 sorted it, since it is fitted at Step 11.54 and reused in place at Step 14.29.

## Hardware (all kit spares except the purchase)

8 × M3×5×4 heat-set insert, 4 × M3×30 SHCS (fan and grill), 2 × M3×8 SHCS (access cover), VHB tape; the
mounts reuse the exhaust cover's 2 × M5 roll-in T-nut and 2 × M5×10 BHCS (Ch 11 Step 11.55), and the two
M3×12 SHCS and the PTFE coupler come off the cover too. Bought (Ch 00
Step 00.8): a 60×60×20 mm 24 V fan, a 1 m JST-XH 2-pin extension, carbon filter mat. Counts from the Voron
2.4r2 assembly CAD and manual p.250–256; design record `review/2026-10-03-exhaust/DESIGN.md`.

## Upstream changes

A `CHANGED VoronDesign/Voron-2` line from `sources_verify.py` means: compare `STLs/Exhaust_Filter/` across
the two commits, and re-fetch and re-slice before printing if any of these files moved.

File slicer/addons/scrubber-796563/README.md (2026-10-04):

# Nozzle scrubber with sheet stops — add-on (Ch 13 Part L)

Optional. On no plate, in no batch (B00–B11), in no run total. **Printed only after Ch 13 Step 13.47 has
decided the parts from this machine's measurements — never ahead of kit day, never from the files below
without that decision.**

## Licence and credit

**CC BY-NC-SA 4.0** (<https://creativecommons.org/licenses/by-nc-sa/4.0/>). Derived from **jinetix**,
*Voron 2.4 Silicone Nozzle Scrubber w/ Sheet Stops (Beacon / Carto Compatible)*,
<https://www.printables.com/model/796563> (CC BY-NC-SA). `source/10mm Bed.stp` is the author's file,
unchanged (Printables file id 5160571, 308 070 bytes, sha256
`64c88c0a3bc9dda1bc6bcfc9f958f10b1b4e32f413ab20ecb1c58e22a790fb9c`). The macros in Ch 13 Step 13.52 are
adapted from the same page (macro revision 2025-12-22). Every file `remix.py` writes is a derivative under
the same licence.

## How the parts are made

`remix.py` is the only generator. It reads `source/10mm Bed.stp`, mirrors the parts for the left bed
extrusion, lowers the A1-wiper seat by **L** and trims the 350 mm bucket by **T**:

| Step | What | Where |
|---|---|---|
| 13.44 | plate rear edge straight at the brush; bare top on both bed extrusions (≥ 39 mm); probe collar clear of the right one | steel rule, machine off |
| 13.45 | **H** flex-plate top above the bed-extrusion top; **w** wiper height | caliper, machine off |
| 13.46 | **d** Omron face above the nozzle tip; **G** Omron face above the extrusion top at Z0; **O** reach past the plate edge | caliper + homed machine |
| 13.47 | calculator (layout rows), then `venv-cq/bin/python slicer/addons/scrubber-796563/remix.py --H … --w … --d … --G … --O …` | laptop |
| 13.48 | print what it wrote to `measured/` (gitignored) | Core One+ |

Decision (heights above the bed-extrusion top; 0.3 mm margin; first layer at Z 0.2; scrub 0.5 mm into
the bristles; S 17.77 seat floor, F 18.85 bracket top, K 20.47 sheet-stop head top, B 21.39 bucket wall,
all read from the STEP and asserted by `remix.py`):

| Quantity | Rule | Why |
|---|---|---|
| L | ≥ S + w + 0.1 − G | the Omron clears the wiper while the plate's rear rows print |
| L | ≤ w − 1.88 | the nozzle at scrub height clears the bracket top on the flick path |
| T | ≥ B + 0.1 − G | the Omron clears the bucket walls while the rear rows print |
| T | ≥ B − S + 0.8 + L − w − d | the Omron clears the bucket walls while the nozzle scrubs |
| sheet-stop screws | fit only if G ≥ K + 0.1 and H ≤ 21.0 | Omron clears the heads; the heads reach the flex plate's edge |
| no-go | O < 3.5, G < 19.75, \|G − (H + d)\| > 0.3 | no reach; no L satisfies both L rows; inconsistent measurements |

L and T round up to 0.5 mm (0 = stock). The printout also gives the two inspection readings for Step
13.49 (bracket base to bristle tips, bucket height) and the expected `z_scrub` for Step 13.51.

## Files here

The committed STLs are the generator's **default**, `remix.py --defaults`, for the expected numbers
(H 20.05 from the author's LDO 10 mm assembly, official wiper w 3.85, d 0.6, O 4.5): L 1.5, T 1.5, sheet
stops fitted. They exist so the pipeline and the print estimate can be checked; print them only if the
Step 13.47 printout names exactly these files. `slicer/stl/MANIFEST.sha256` pins them and `source/10mm Bed.stp`
(`slicer/plates.py` `ADDONS`); `python3 slicer/fetch_stls.py --verify` fails if any of the four changes.
`remix.py --defaults` is byte-reproducible, so regenerating them must leave `--verify` green.

| File | Change from the author's part | Qty |
|---|---|---:|
| `brush_bracket_L1.5_MIRROR.stl` | mirrored; wiper seat and its posts lowered 1.5 mm | 1 |
| `bucket350_T1.5_MIRROR.stl` | mirrored; top trimmed 1.5 mm | 1 |
| `stop_bracket.stl` | none (symmetric) | 1 |

## Print

One job on the Core One+, smooth sheet, `slicer/voron-coreone-asa.ini` (Voron spec: 4 walls, 5 top/bottom,
40 % grid, 0.2 mm), Galaxy Black ASA, as oriented, **no supports**. Default set, PrusaSlicer 2.9.6 CLI
estimate: **38.5 g, 2 h 30 m**. The parts go in bin `13-scrubber` (`slicer/bins.py` `ADDON_PARTS`; its
label is on the bin-labels sheet and names them generically, since the file names come from `measured/`).

## Upstream changes

`sources.yml` pins the Printables page (`printables-796563-nozzle-scrubber`): file ids and sizes, and a
hash of the macro text. A `CHANGED` line from `python3 scripts/sources_verify.py` means: download the new
`10mm Bed.stp`, diff it against `source/`, re-run `remix.py --defaults` and the measured set, and re-diff
the page's macros against Ch 13 Step 13.52's block before printing anything.

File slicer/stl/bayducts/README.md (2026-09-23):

# bayducts — STLs for batch B11 (bay ducting, layout v3)

Print page: `docs/manual/print/B11-bay-ducting.md`. Plates: `slicer/plates.py` (B11-P1…P5).

## Licence and credit

GPL-3.0. Every file here is, or is derived from:

- **MyStoopidStuff**, *Remix of RyanDam's Cable Management Duct for Voron Printers, Version 3.2*,
  <https://www.printables.com/model/502306> (GPL 3.0), itself a remix of
- **RyanDam**, *Cable Management Duct* for Voron printers.

The files under `remix/` are **remixed for the LDO Rev D+ bay** (Voron 2.4 R2 350) in this repo,
2026-09-23, and are distributed under the same GPL-3.0 terms. The scripts that made them are in
`review/2026-09-23-bay-mods/layout-v2/work/remix.py` and `layout-v3/work/remix_v3.py`; the GPL
text is at <https://www.gnu.org/licenses/gpl-3.0.html>.

## Layout

| Folder | What | In git? | How it gets here |
|---|---|---|---|
| `mss/502306/` | MSS stock pieces, byte-for-byte | no (gitignored) | `python3 slicer/fetch_stls.py`, by Printables file id (`slicer/plates.py` `PRINTABLES`) |
| `remix/` | the V2L_* / V3L_* remixes | yes | committed; `fetch_stls.py` only hashes them |

`slicer/stl/MANIFEST.sha256` pins both. `python3 slicer/fetch_stls.py --verify` fails if a file here
differs from it.

Four `mss/502306/` files are on no plate: `CMD_V3_1H_T_REG` and `CMD_V3_1H_82mm_DUCT` (+ covers) are
the fallback middle joints if the Leviathan-to-PSU gap measures under 25 mm; `CMD_V3_1H_142mm_DUCT`
(+ cover) and `CMD_V3_1H_WIRE_BOX` are parents the remix scripts cut custom lengths from.

## What each remix is

| File | From | Change |
|---|---|---|
| `V3L_COUPON_22N_DUCT` + `_COVER` | v2's 22 mm straight | narrowed 2.4 mm like the 154N; lid-snap test coupon |
| `V3L_154N_DUCT` + `_COVER` | `CMD_V3_1H_154mm_DUCT` | slice-and-shift Δ2.4 mm: 22.0 mm outer, walls/tines/snap unchanged |
| `V3L_T_REG_N` + `_COVER` | `CMD_V3_1H_T_REG` | stem narrowed by the same cut; bar 81.6 mm |
| `V3L_10mm_DUCT` + `_COVER` | `CMD_V3_1H_82mm_DUCT` | shortened to 10 mm |
| `V3L_34mm_DUCT_HOLE`, `V3L_34mm_DUCT_COVER` | `CMD_V3_1H_82mm_DUCT` | 34 mm, 17 × 16 mm floor opening over the bed-lead hole |
| `V3L_90DEG_R15` + `_COVER` | `CMD_V3_1H_90DEG` | arc only, re-radiused R22 → R15.5 |
| `V3L_WIRE_BOX_PORT` | `CMD_V3_1H_WIRE_BOX` | original size, 4 pinched edges repaired, one 18 mm port in the front wall |
| `V2L_90DEG_MIRROR`, `V2L_90DEG_COVER_MIRROR` | `CMD_V3_1H_90DEG` + cover | mirrored |
| `V2L_58mm_DUCT`, `V2L_130mm_DUCT`, `V2L_70mm_DUCT` (+ covers) | 154 / 142 / 82 mm ducts | shortened |
| `V2L_STRIP_FIN` | new | divider fin between PSU −V and FG |

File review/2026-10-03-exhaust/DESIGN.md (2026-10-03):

# Chamber exhaust fan — design record (2026-10-03)

Alex's decision (2026-10-03): one chamber exhaust fan, driven by the chamber thermistor through Klipper, so PLA
(~35 °C) and PETG (~40 °C) print in a cool, steady chamber; every other cooling or venting mod is deferred. After the
build he prints mostly PLA/PETG, ASA only occasionally.

**Decision in one line:** the stock Voron 2.4r2 exhaust housing over the stock back-panel notch (no cutting), a 24 V
6020 on Leviathan FAN0 (`PB7`) with a third 24 V jumper, `[temperature_fan exhaust_fan]` reading the existing
`chamber_temp` through a `temperature_combined` sensor, `watermark` control, ceiling per filament from PrusaSlicer's
native *Chamber temperature* fields via `PRINT_START`, ASA never vented. Ch 14 Part H, Steps 14.25–14.36.

## Folder

| File | What |
|---|---|
| `exhaust.cfg` | the Klipper block, byte-identical to Ch 14 Step 14.33's (the test asserts it) |
| `test_macros.py` | `.venv/bin/python review/2026-10-03-exhaust/test_macros.py` — macros rendered with Klipper's Jinja delimiters; `PRINT_START` (Ch 12 12.36 block) and LDO's `PRINT_END` with the inserted lines; Klipper's own `temperature_fan.py` + `temperature_combined.py` at `f0892d8` driven by a mock `chamber_temp`; since the 2026-10-03 follow-up also the Nevermore gating (`FILAMENT=`), `_EXHAUST FILTER=` and `_NEVERMORE_SCRUB`. PASS 2026-10-03, 35 checks |

## 1. Physical exhaust

**Stock housing exists and fits without cutting** (verified):
- Voron-2 `STLs/Exhaust_Filter/` at the pinned `a192410`: `exhaust_filter_housing`, `[a]_exhaust_filter_mount_x2`,
  `[a]_filter_access_cover`, `[a]_exhaust_fan_grill`, `exhaust_filter_grill`. Manual p.250–256.
- Stock `Drawing_DXFs/Panels/350_Back_Panel.DXF` = 483 × 503 mm with a centred notch in the top edge, 147 mm wide ×
  42.5 mm deep. The LDO back panel is 483 × 503 × 3 mm (Ch 11 11.55), and LDO ships `exhaust_cover.stl` "with the
  stock exhaust grill to seal the back panel" (print plan l.598): the LDO panel carries the stock notch. Bench
  confirmation is gate row 1 of Step 14.25.
- The kit's printed set already has `exhaust_filter_grill` (B09-P3, fitted at 11.54); the other four were listed as
  skipped (print plan l.600, l.837). They are now an add-on print outside the plates, like the scrubber.
- Geometry from the cached 2.4r2 assembly CAD (`~/.cache/voron-cad/cache/index.json`): grill in the notch plane, flush
  with the panel's outer face; two mounts on M5 drop-in T-nuts in the top rear extrusion's back slot; housing taped
  (VHB) to the panel's outside, projecting ~48 mm, fan grill to ~62 mm. M3×12 ×2 through the grill into the housing
  from inside. Hardware in the CAD: 8 M3 inserts, 4 M3×30, 2 M3×12, 2 M3×8, 2 M5×10 BHCS (+2 M5 T-nuts per p.254).
  All kit spares (`parts.py --ledger`: inserts 153/122, M3×30 44/17, M3×12 50/32 — the two come off the cover, M3×8
  283/207, M5×10 BHCS 54/35, M5 roll-in T-nut 80/68).
- **Fan: 60×60×20, 24 V.** CAD solid "6020 Fan"; the screw stack confirms it (M3×30 = 3.2 grill + 20 fan + ~6.8 in
  the insert; a 6025 would leave 1.8 mm). The kit's two 6020s are the bay pair (BOM qty 2, both fitted at 10.47), so
  one is bought. Leviathan fan channels are 0.5 A each (README); a 6020 draws ~0.1 A.
- **Connector:** Leviathan V1.3 `FAN_0` = J22, `JST_XH_B3B-XH-A` (3-pin XH 2.5, power/GND/tach) per the KiCad
  schematic @878c3c4; LDO's `voron2_leviathan.cfg` @878c3c4: FAN0 `PB7`, tach `PB8`; FAN1 `PB3`. A 2-wire fan's 2-pin
  XH plug sits on the power pins; Step 14.31 copies FAN2's red-wire position (no crimper owned). Buy a 1 m XH 2-pin
  extension; Step 14.25 measures the route (gate ≤ 1250 mm).
- **Cable route (bench item):** the fan is outside the chamber; its lead is fed inside the housing on the intake
  side, out through a grill opening, down the back panel's inner face on VHB tie points, into the bay through the
  Z-chain notch beside the FILTER FAN lead (layout v3 keeps DC out of the round hole). Nothing in the Part cuts or
  drills to make a route; the gate stops the add-on if none exists. Not found in any source: how stock 2.4 builds
  route this lead (Voron's gantry-wire table explicitly excludes the exhaust fan).
- **PTFE:** the LDO cover's centre hole is threaded (Ø ~8.9–9.6 modelled, i.e. a 1/8 BSPP-class coupler) and the
  stock housing's top boss is the same class (Ø ~9.1–9.9) with a Ø ~4.4 PTFE channel. The manual never fits the kit's
  "4mm Bowden Coupler"; if the PTFE runs through the cover, the coupler moves to the housing boss `(verify on bench)`.
- **Clearance:** gate row 2 wants ≥ 100 mm free behind the notch (62 mm housing + outlet room).

**Fumes.** The stock filter bay holds a stack of mat (six 7 mm layers in the CAD, 130 × 65 mm). Part H fits two
layers of cuttable activated-carbon cooker-hood mat: some odour capture, little flow loss. Rationale: ASA is never
vented (its fumes stay with the Nevermore, as designed); PLA/PETG venting through a thin mat matches how Alex already
runs the Core One+ (AFS bypass flaps vent PLA/PETG unfiltered, Filter All Materials off). Step 14.36's fallback order
if the ceiling cannot be held: one layer out → door ajar. Voron's own note (Voron-Documentation
`tuning/filament_tuning.md` @b8c014f): "with enclosures, some filaments such as PLA may need to have the doors opened
and the exhaust fan running (and even the sides removed)". Expect a ceiling, not air conditioning.

**Not a STOP.** No panel cutting, drilling or remix; the cover swap is reversible (keep the cover). The only open
choices left to Alex are in § 6.

## 2. Klipper

```ini
[temperature_fan exhaust_fan]   # full block: exhaust.cfg / Step 14.33
pin: PB7
sensor_type: temperature_combined
sensor_list: temperature_sensor chamber_temp
combination_method: max
maximum_deviation: 999.9
control: watermark
max_delta: 2.0
target_temp: 0
min_speed: 0.0
max_speed: 1.0
shutdown_speed: 0.0
kick_start_time: 0.5
min_temp: 0
max_temp: 100
```

- **Sensor: `temperature_combined`, not a converted sensor or `duplicate_pin_override`.** Klipper refuses a pin
  declared twice; `[duplicate_pin_override]` is documented as "for diagnostic and debugging purposes … may cause
  confusing and unexpected results". Converting `chamber_temp` into the fan renames the object, which breaks Ch 12
  12.36's `TEMPERATURE_WAIT SENSOR="temperature_sensor chamber_temp"`, Ch 14 14.8's reading, Ch 13's checks and the
  Checkpoint lines. A combined sensor with one member reads `chamber_temp`'s value every 0.3 s, so nothing existing
  changes: Mainsail keeps `chamber_temp` and adds `exhaust_fan` (temperature + target + speed), `M105` keeps
  `chamber_th`, no macro edits. Source-verified at `f0892d8` (= master 461c4e3, identical blobs): `temperature_fan`
  calls `heaters.setup_sensor()`, `temperature_combined` is auto-loaded from `temperature_sensors.cfg` and implements
  `setup_minmax`/`setup_callback`/`get_report_time_delta`. Klipper's docs list extruders/heater_generic/heater_bed as
  users; `temperature_fan` is not named but uses the same factory. `test_macros.py` instantiates the real classes.
- **`min_temp: 0` is required**, not cosmetic: the combined sensor starts at 0.0 and its timer compares against
  `min_temp` before `chamber_temp` has reported; `min_temp: 5` shuts Klipper down at boot (test shows it).
- **No `gcode_id`:** `chamber_th` already reports the same reading in `M105`; a second id adds nothing (Mainsail reads
  objects, not M105).
- **`watermark`, not `pid`:** Klipper has no `PID_CALIBRATE` for a temperature_fan, so gains would be guesses; the
  plant is slow (minutes) and the sensor moves with the toolhead, so a PID would chase position; Klipper's PID path
  floors the fan at `min_speed` whenever a target is set (`max(min_speed, max_speed − co)`), which is the opposite of
  "off when cool". Watermark: off below ceiling − 2, flat out above ceiling + 2; the 4 °C band is irrelevant to
  PLA/PETG. Same choice as the Voron community page.
- **`target_temp: 0`**: `set_tf_speed` forces 0 whenever the target is ≤ 0, so 0 = off regardless of temperature;
  the fan does nothing until a print sets a ceiling, and every `RESTART` returns it there.
- **`shutdown_speed: 0.0`** (temperature_fan's default is full on): matches LDO's stock `[heater_fan exhaust_fan]` and
  `[fan_generic nevermore]`; a fault cuts the heaters anyway.
- **Macros:** `_EXHAUST CHAMBER= TARGET=` (called first thing in `PRINT_START`, after `SET_GCODE_OFFSET Z=0`): any
  print that waits for chamber heat (`CHAMBER > 0`) or asks a ceiling above `hot_above` = 45 °C is a hot-chamber
  material → ceiling 0; it also cancels a pending purge timer, so a print started within 10 min of the last one keeps
  its ceiling. `_EXHAUST_PURGE` (in `PRINT_END` after `TURN_OFF_HEATERS`): after a vented print, ceiling 1 °C = flat
  out for `purge_min` = 10 min, then `[delayed_gcode _EXHAUST_OFF]` sets 0; after an unvented (ASA) print, 0 at once
  and the Nevermore keeps running as before. No `M141` macro: one owner (`PRINT_START`), and PrusaSlicer emits
  `M141` only with automatic temperature commands on, which Ch 13 13.41 turns off for good reason.

Chamber thermistor placement (LDO `cw2_captive_pcb_cover`, CT = `nhk:PB2`, Ch 08 08.51): good enough to control a
ceiling. Bias: it rides on the toolhead, in the bed's plume at low Z and near the hotend and its fan exhaust, so
during a print it reads warm against mid-chamber air (magnitude not measured; Step 14.36 Tip suggests a reference
thermometer). For a ceiling that errs safe: the fan runs a little more, the real chamber sits a little under the
setting. It also wanders with toolhead position; `max_delta` 2 absorbs that. For ASA the fan is off, so the bias does
not matter. A fixed mid-chamber thermistor on a spare Leviathan `TH` port would be the upgrade if the log shows a
problem (not proposed now: it is a purchase and a wire).

## 3. PrusaSlicer 2.9.6

Printer preset `Voron 2.4 350`, start G-code (one line, replaces Ch 13 13.41's):

```
PRINT_START BED=[first_layer_bed_temperature] EXTRUDER=[first_layer_temperature] CHAMBER={chamber_minimal_temperature[initial_tool]} EXHAUST={chamber_temperature[initial_tool]}
```

End G-code stays `PRINT_END`. **No filament start/end G-code lines.** Per filament, Filament Settings → Chamber
temperature (Expert mode; `comExpert` in PrintConfig.cpp) — Nominal / Minimal:

| Preset (the ones printed on the Voron) | Nominal → ceiling | Minimal → `CHAMBER` wait | Prusa vendor values (2.5.11) |
|---|---|---|---|
| PLA | 35 | 0 | 20 / 0 |
| PETG | 40 | 0 | 35 / 0 |
| ASA | ignored (fan off) | Ch 14 14.8 settled − a few °C | 55 / 40 |

Why native fields, not filament G-code or an `M141` macro: (1) filament start G-code runs after `PRINT_START`, too
late for the soak; (2) Prusa uses the same two fields with the same meaning on the Core One (fans hold the chamber at
or below Nominal; the printer waits for Minimal), so the value sits where PrusaSlicer users look; (3) it also fixes a
latent hang: `CHAMBER` was one printer-level number, so raising it for ASA after 14.8 would make every PLA print
`TEMPERATURE_WAIT` forever (no timeout). Minimal 0 = no wait.

Verified with the 2.9.6 CLI (`voron-coreone-asa.ini` + Klipper flavour, automatic temperature commands off, these
two fields): PLA → `PRINT_START BED=60 EXTRUDER=215 CHAMBER=0 EXHAUST=35`, PETG → `… CHAMBER=0 EXHAUST=40`, ASA →
`… CHAMBER=40 EXHAUST=55`; no `M141`/`M191`/`M190`/`M109` emitted. Source: `GCode.cpp` @version_2.9.6
l.1981–2001 writes chamber commands only when `autoemit_temperature_commands` is on. With vendor values untouched,
PLA's 20 still works (fan runs more) and ASA stays off via `hot_above`.

Where the manual says it: a step (14.35), because it is an action in the add-on; no frozen step edited.

## 4. Manual placement

Ch 14, new **Part H** after 14.24, before the Tuning log and Checkpoint 14 (Ch 14 has no What-if section). Why not
Ch 13 like the scrubber: the housing needs the back panel on (Ch 11 Part B, after Ch 13), and the test needs Ch 14
14.8's settled ASA number to prove the closed housing does not leak the 50–60 °C band. The intro says Ch 10's "exactly
two jumpers" / "FAN0 empty" checks describe the machine before the add-on; 14.31's ⚠ and Check state the new count.

| Step | Title | Kind | Helper |
|---|---|---|---|
| 14.25 | Inspect the back of the machine before anything is bought (gate-calc `exhaust-fit`) | off | yes |
| 14.26 | Print the exhaust parts on the Core One+ | bench | yes |
| 14.27 | Set the eight heat-set inserts in the housing | **iron** | – |
| 14.28 | Build the fan and the filter into the housing | **blade** (scissors) | – |
| 14.29 | Swap the exhaust cover for the housing | off | yes |
| 14.30 | Shut down, unplug and prove it dead | **mains** | – |
| 14.31 | Plug the lead into FAN0 and jumper it for 24 V | **mains** (bay open) | – |
| 14.32 | Close the bay and power on, hand on the switch | **mains** | – |
| 14.33 | Add the exhaust fan to `printer.cfg` | on | yes |
| 14.34 | Test the fan by target, then on a hot chamber (gate-calc `exhaust-test`) | **hot** | – |
| 14.35 | Give PrusaSlicer the exhaust ceiling | laptop | yes |
| 14.36 | Print PLA under a 35 °C ceiling, log it, shut down | **hot** | – |

`hooks/mascot.py` `NO_MASCOT_STEPS`: mains 14.30–14.32, iron 14.27, blade 14.28, hot 14.34 14.36. Six Pause
segments (Sessions 14 → 20 with Part H). Header, Hardware table, tuning-log rows, Checkpoint 14 optional line, 00-index
row 31 + chapter table, Ch 00 00.8 buy row, print README add-on row, print plan l.600/l.837 notes, and Ch 15's
two "exactly two jumpers" lines (tap-tree leaf + table) now add "three with Part H".

## 5. Purchases

| Item | Rough price | Source |
|---|---|---|
| 60×60×20 mm 24 V fan, 2-wire, ball bearing (XH 2.54/2.5 plug if offered) | ~$10 | Amazon / any electronics shop (e.g. GDStime, Winsinn 6020 24 V) |
| JST-XH 2-pin extension lead, 1 m (1.5 m if 14.25's string > 1250 mm) | ~$7 (multi-pack) | Amazon |
| Activated-carbon cooker-hood filter mat, cuttable | ~$10 | Amazon / hardware store |

Not bought (kit spares): screws, inserts, T-nuts, VHB, zip ties, the third jumper (Ch 09 bag holds five, Ch 10 uses
two). Not bought: a JST crimper (the plug and FAN2's pattern avoid crimping).

## 6. Open — Alex / bench

1. **Bench:** the LDO back panel has the stock notch, free depth ≥ 100 mm, the extrusion's back slot reachable, a lead
   route without cutting, route length (14.25). If no route: STOP — any hole is Alex's call, outside Part H.
2. **Bench:** the kit coupler threads into the housing boss, if the PTFE ran through the cover (14.29).
3. **Bench:** FAN0 polarity by FAN2's plug; a 2-pin XH plug seats on the 3-pin header's power pins (14.31).
4. **Bench:** the closed housing still lets ASA settle at 50–60 °C (14.34); the 35 °C ceiling holds with the door shut
   (14.36). Unknown until measured: whether a 6020 through two mat layers is enough (Voron's own note says maybe not).
5. **Alex (optional):** filter choice — two carbon layers (default), none (max flow, consistent with the Core One+
   PLA/PETG practice), or the full stack.
6. Not verified on real Klipper/Mainsail: the macros and the combined-sensor path ran only offline (test_macros.py,
   real Klipper classes with mocks). Mainsail's display of a `temperature_fan` (target box, speed) is expected, not seen.

## Side findings (outside this task, not acted on)

Follow-up 2026-10-03 (same day): the first, third and fourth findings below are fixed in the manual (13.41 machine
limits and binary G-code; 11.42/11.54/11.55 grill inside, cover outside with two inserts, two M5 tabs and the
PTFE coupler, 14.29 reusing them; 12.36 `FILAMENT=` gating with `_NEVERMORE_SCRUB`, and `_EXHAUST FILTER=`
so a filtered material is never vented). The 13.41 claim was confirmed with the 2.9.6 CLI; the GUI switches
*How to apply limits* to *Use for time estimate* itself when the flavour changes (`Tab.cpp` @version_2.9.6).

- Ch 13 13.41 switches the copied Core One printer preset to Klipper flavour but does not change *Machine limits*;
  the 2.9.6 CLI refuses to export ("Machine limits cannot be emitted to G-Code when Klipper firmware flavor is used")
  until `machine_limits_usage` is `time_estimate_only` or `ignore`. The GUI likely says the same at export. Worth a
  line in 13.41.
- The copied Core One filament presets emit `M572 S…` (Prusa pressure advance) from their filament start G-code;
  Klipper answers "Unknown command" (harmless). PA lives in Klipper per Ch 14.
- Ch 11 11.54 says "cover on the inside face, grill on the outside"; the stock CAD puts the grill in the notch plane
  with the housing outside, and LDO's cover has two top tabs that look like the stock mounts' M5 holes. 11.54 is
  already `(verify on bench)`. The manual never fits the kit's `4mm Bowden Coupler` nor says where the PTFE crosses the
  back panel (probably the cover's threaded centre hole).
- `PRINT_START` turns the Nevermore on for every print, PLA included, spending carbon on materials that do not need
  it.

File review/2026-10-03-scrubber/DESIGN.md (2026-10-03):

# Nozzle scrubber with sheet stops — design record (2026-10-03)

> **Superseded in part, 2026-10-03 (follow-up).** Nothing is printed ahead any more: Ch 13 Part L is now Steps 13.44–13.54 (inspect → measure → decide → print → fit), and `slicer/addons/scrubber-796563/remix.py` (reading the tracked `source/10mm Bed.stp`) is the only generator, deriving L and T from the measured H, w, d, G and O (rules in that folder's README). `remix_low.py` below was its prototype and is removed; `ch13-append.md` is the first draft of Part L. Geometry, sources and § 3/§ 4 analysis here still stand.

Add-on for the end of Ch 13: jinetix's "Voron 2.4 Silicone Nozzle Scrubber w/ Sheet Stops (Beacon / Carto
Compatible)", Printables 796563. Research only; no existing file was edited.

**Decision in one line:** print the 10 mm-bed set as a **low-profile remix** (wiper seat −1.5 mm, bucket
−2.0 mm), mirrored to the **left** bed extrusion, as an **add-on print outside the plate system** (38.3 g
black ASA, 2 h 30 m); hardware all from kit spares; buy only the Bambu A1 wiper (3-pack, $2.99). Fit as
Steps 13.44–13.50 in a new Part L; the macro clamps its circles to this build's ~4–5.5 mm reach past the plate.

## Folder

| File | What |
|---|---|
| `src/description.txt`, `src/print.json`, `src/comments.txt` | Printables page text (BOM, macros), metadata, all 100 comment lines (2026-10-03) |
| `src/10mm Bed Setup.3mf`, `src/10mm Bed.stp`, `src/8mm Bed Setup.3mf` | author's files (no STLs exist on the page) |
| `src/Voron 2.4 Decontaminator.stp` (25 MB), `src/MRW Kit*`, `src/img/*.jpeg` | full assembly incl. 10 mm LDO bed, MRW kinematic-bed variant, photos — gitignored (`.gitignore` here) |
| `src/leviathan-printer-rev-d-sbv2.cfg` | LDO config @667521d, for the section placement |
| `stl/jinetix_10mm_*.stl` | the 5 objects of `10mm Bed Setup.3mf`, print-oriented; `_MIRROR` = left-side copies |
| `stl/low/*.stl` | low-profile remix (recommended), from `remix_low.py --lower 1.5 --trim 2.0` |
| `remix_low.py` | cadquery remix from `src/10mm Bed.stp` (`venv-cq/bin/python remix_low.py --lower L --trim T`) |
| `scrubber.cfg` | Klipper block to paste (§ 4) |
| `test_macros.py` | renders the macros with Klipper's Jinja delimiters and a mock printer; asserts the G-code (PASS, below) |
| `ch13-append.md` | Steps 13.44–13.50 exactly as they would be appended (§ 6) |

Re-fetch: Printables GraphQL `getDownloadLink(id, printId:"796563", fileType:stl)`; file ids: `10mm Bed Setup.3mf`
5160570, `10mm Bed.stp` 5160571, `8mm Bed Setup.3mf` 5160556, assembly STEP 5159481, MRW 10 mm 6276608/6276609.
3MF/STEP files are listed under `stls`, so `fileType:stl` works for them. Comments: `comments(targetObjectId:796563,
targetType: print){ text created author{publicUsername} replies{...} }` (field is `text`).

## 0. Earlier-session facts, re-verified

| Claim | Verdict | Evidence |
|---|---|---|
| Printables 796563 by jinetix, CC BY-NC-SA | ✓ | `print.json`: user `jinetix`, licence "Attribution — Noncommercial — Share Alike"; published 2026-01-16; 331 likes, 18 makes |
| has 10 mm-bed and 350 files | ✓, as **one 3MF** | `10mm Bed Setup.3mf` holds 5 objects: 300/350/centre buckets, brush bracket ("Decontaminator"), stop bracket. Names from `10mm Bed.stp`, matched by volume |
| Bambu A1 wiper pad | ✓ | description l.12–18: official 8×37×3.85 mm, clone 8×37×4 mm (bristles ~0.2 mm taller) |
| 4× 6×3 mm magnets | ✓ | description BOM; STEP: 2 Ø6.2 pockets in the bracket (open downward, 3.16 deep) + 2 in the bucket (open upward, 2.64 deep), facing through ~1.1 mm of plastic |
| needs `[gcode_arcs]` | ✓ | description l.29–30 (`resolution: 0.1`) |
| ≥ 6–7 mm Y travel past the plate | ✓ as stated; **this build has ~4–5.5 mm** | description l.2, l.24 ("typical 10mm extra Y overtravel"); § 3a |
| kit brass brush used by 796563 | ✗ | 796563 uses only the silicone A1 wiper. The kit's `Brass Brush` is a hand tool (`hardware-ownership.yml` `unreconciled: tool`; `00-before-you-start.md` l.317, l.329) |
| MRW files | not for us | "MRW Kit" = parts for the MRW kinematic bed mount (assembly solids `MRW Kinematic Ball`, `MRW Wings`), ~16 mm taller |

Author's own text calls the macros `CLEAN_NOZZLE_PARK`/`CLEAN_NOZZLE` in "Macro Placement"; the cfg names are
`NOZZLE_PARK_BUCKET`/`NOZZLE_CLEAN` (description l.26 vs l.32, l.75).

## 1. Printed parts

LDO plate is **355×355×10 mm** (`ldo-350-bom.yml` l.793; Ch 03 l.3) → the **10 mm** set. Bed extrusions are
150 mm c-c (Ch 03 l.18), as in the author's CAD (±75 mm). Kit uses **no printed sheet stops**: the print plan lists
`Purge Bucket/brush_holder_sheet_stop` + `individual_sheet_stop` only as optional, unprinted (plan l.809–813);
`slicer/plates.py` has no sheet_stop/brush_holder entry. Nothing is replaced.

| Part (source object) | Qty | Recommended file | Size, mm | ASA spec mass / time |
|---|---|---|---|---|
| brush bracket ("Decontaminator") | 1 | `stl/low/brush_bracket_low1.5_MIRROR.stl` | 61.3×38.0×18.9 | 9.4 g / 40 m |
| stop bracket | 1 | `stl/jinetix_10mm_stop_bracket.stl` (symmetric, no mirror) | 20.0×38.0×17.5 | 4.6 g / 24 m |
| 350 mm bucket | 1 | `stl/low/350mm_bucket_trim2_MIRROR.stl` | 93.0×38.0×24.9 | 24.3 g / 1 h 31 m |
| **plate (3 parts)** | | | | **38.3 g / 2 h 30 m** |

Stock (un-remixed) set for comparison: 9.7 + 4.6 + 24.8 = 39.1 g, 2 h 34 m. Estimates: PrusaSlicer 2.9.6 CLI,
`slicer/voron-coreone-asa.ini` (4 perimeters, 40 % grid, 5/5, 0.2 mm, shrinkage comp 0 %, no support), parts
merged on one bed, not GUI-arranged. Orientation: as drawn, flat base down; **no supports** (author's 3MF:
`enable_support 0`, 4 walls, 40 %, 5/5, 0.2; author: "turn off shrinkage compensation"). Colour: Galaxy Black.
A blue-accent bucket would need its own plate; not worth it.

Remix (`remix_low.py`): bracket wiper seat floor 37.77 → 36.27 (posts moved down with it; seat-centre ray cast
17.77 → 16.27 in print frame); bucket top 41.39 → 39.39. Both re-slice clean. Licence: a CC BY-NC-SA derivative —
if committed to the public repo, ship with attribution + same licence (B11 precedent: `slicer/stl/bayducts/README.md`).

## 2. Hardware and purchases

| Item | Qty | Use | Source |
|---|---|---|---|
| M3×8 SHCS | 6 | 2 bolts per bracket (Ø3.2 through, Ø5.7 counterbore, 2.93 mm floor) + 1 upright sheet stop per bracket, self-tapped into a Ø3.0 bore | kit: ledger 207/283 after this |
| M3 roll-in T-nut | 4 | top slot of each bed extrusion behind the plate (holes on the slot centreline) | kit: 128/135 |
| 6×3 mm neodymium magnet | 4 | 2 bracket, 2 bucket | kit: 12/16 (Nevermore uses 8) |
| super glue | – | only if a magnet is loose | consumable (11.34 precedent) |
| **Heatbed Nozzle Wiper – A1/A2L** | 1 (3 in the box) | the brush | **buy**: Bambu Lab US store, $2.99, in stock 2026-10-03, "In the Box … ×3"; free shipping only over $59 |

Ledger numbers: `python3 scripts/parts.py --ledger` on a scratch copy with the draft spliced in. Sheet-stop length:
assembly SHCS solids are 11.0 mm overall (3 head + 8); the stop bracket's blind bore is ~11.4 mm deep, so M3×12
would bottom out. Author's BOM names no T-nuts; the brackets need them.

## 3. Mounting position and geometry

Frame: y0 = plate rear edge. Author's assembly: brackets' front faces butt the plate's rear edge; the wiper spans
y0 … y0+8 (bristle field ≈ y0+0.5 … y0+7.5); the bracket footprint runs y0 … y0+38.25 on the extrusion top.

**Side: left bed extrusion, mirrored** (brush and bucket outboard-left), stop bracket on the right extrusion. The LDO
nozzle probe is on the **right** extrusion's inner face (Step 09.30; LDO build-plate mapping); flicked ooze then lands
far from the pin. Machine-X estimate if the plate is centred on X175: left extrusion X 90–110; bristles ≈ X 51–87;
bucket X ≈ −3…90; bucket park X ≈ 41 `(verify on bench)`. Room behind the plate: frame 470, plate front 38 mm behind
the frame front (Ch 03 03.16) → rear edge at 393, rear rail inner face at 450 → 57 mm free vs 38.25 needed.

**(a) Y travel past the plate (O).** The nozzle reaches Y_max only where the nozzle-probe pin is: Step 13.24 slides the
probe until the Ø5 shaft is under the nozzle at the rear limit with a 2–3 mm gap to the plate (Voron p.161: 1.5 mm).
So O ≈ gap + 2.5 = **4.0–5.5 mm** (inference; stock configs in both LDO and Voron files are Y 350/350). The author's
default macro scrubs up to y0+6 and wants O ≥ 6–7. Users on 350 machines with reduced travel cut `brush_depth` to 2
or moved the plate forward 3–5 mm (comments: Mazvydas, dobromyslov). Our macro clamps: circle Y from y0+1.5 to
Y_max−0.5, radius = min(2, (O−2)/2); O 4.0 → r 1.0, 5.5 → r 1.75, < 3.5 → refuses. Optional upstream tweak: Step 13.24
could ask for the 3 mm end of its gap (O ≈ 5.5) when the add-on will be fitted.
Plate rear edge: the manual says the pin "stands in the plate's rear cut-out" (09.30). LDO's Rev C plate photo
(`03-build-plate/build_plate_bottom_view.jpg`) shows a straight cable edge; the "cut-out" seems to come from the
stepped outline of the schematic `ldo-build-plate-mapping.png`. If the 350 plate really is notched at the pin, O at
the brush X could be ≤ 0 and the add-on cannot work: Step 13.44 measures O at the brush X first.

**(b) Brush height vs the Omron.** Heights above the build surface, author's 10 mm assembly (extrusion top z 20,
plate on 7.8 mm thumb nuts, 1.5 mm magnet sheet, 0.75 mm flex plate → sheet top z 40.05, i.e. 20.05 mm above the
extrusion):

| Feature | Stock | Low remix |
|---|---|---|
| wiper top (official / clone) | +1.55 / +1.75 | +0.05 / +0.25 |
| bucket rear and end walls | +1.34 | −0.66 |
| bucket front lip, bracket top | −1.1…−1.3, −1.20 | same |
| sheet-stop heads | +0.42 | +0.42 |

Omron TL-Q5MC2: footprint 17×17 mm (CAD index), centre 25 mm behind the nozzle (`[probe] y_offset: 25.0`, Ch 12
12.29). Let d = Omron face height above the nozzle tip (`z_offset: 0`; Ch 12/13 give no value, Voron docs give no
target — **measure it**, Step 13.44). Requirements with 0.3 mm margin, first layer at Z 0.2, scrub 0.5 mm into the
bristles, no flick dip:

| Situation | Stock needs | Low needs |
|---|---|---|
| printing in the rear 33.5 mm of the plate within ±8.5 mm of the brush X: Omron over the wiper | d ≥ 1.65 (1.85 clone) | d ≥ 0.15 |
| printing near the rear at either extrusion X: Omron over a sheet-stop head | d ≥ 0.52 | d ≥ 0.52 |
| scrubbing (Z = wiper top − 0.5): Omron over the bucket rear wall | d ≥ 0.59 | d ≥ 0.09 |
| **governing** | **d ≥ 1.65** | **d ≥ 0.52** |

Every row shifts by −Δ, Δ = (our extrusion-top-to-sheet-top) − 20.05; Steps 13.44/13.47 measure the real heights
directly, so Δ is never needed as a number. The low remix scrubs at Z ≈ −0.45 behind the plate (Klipper
`[stepper_z] position_min: -5`, Ch 12 12.25), so the macro keeps the circle's front ≥ y0+1.5 and drops Z only over
the bucket. Flick path over the bracket/bucket lip: Z −0.45 vs −1.1…−1.3 → ≥ 0.65 mm.

**(c) Collisions at the bed rear.**
- Nozzle-probe body/collar (right extrusion inner face): Voron CAD puts the Ø16 collar 1.5 mm inboard of the inner
  face and ~5 mm above the extrusion top; the stop bracket overhangs the inner face by 0.23 mm, its Y range covers
  the collar. ~1.3 mm clearance in the Voron geometry; LDO's thicker body unknown → bench check, fallback: no stop
  bracket.
- Sheet-stop heads: centre y0+2.3, Ø5.5 → head front 0.45 mm over the plate edge line, head underside 0.33 mm below
  the plate top in the author's CAD; the head bears on the plate's rear arris/magnet-pad edge. Bench check; if it
  fouls, set the bracket 0.5 mm back.
- Bed WAGO mount: left extrusion **inner side** slot under the plate (Step 09.34), not on the top behind it. Bed leads
  exit the rear edge centre-left: keep them dressed inboard of the left extrusion.
- Nevermore plenum: inner faces between the extrusions (11.38); brackets use the top slot. No conflict.
- Rear frame / Z rails: bucket ends ~19 mm in front of the rear rail; Z rails sit on the rear vertical extrusions.

## 4. Klipper

Author's macros verbatim: `src/description.txt` l.29–30 (`[gcode_arcs]`), l.32–72 (`NOZZLE_PARK_BUCKET`),
l.75–175 (`NOZZLE_CLEAN`; l.175 runs into the closing prose, an HTML-strip artefact), revision 2025-12-22. Adapted block: **`scrubber.cfg`** (paste whole). Changes: one
`_SCRUB` variable block (the author duplicates the brush reference in both macros); bucket side left; Y clamp to
`printer.toolhead.axis_maximum.y` (§ 3a); lift → XY → drop over the bucket (the author's Z-then-XY order drags at
scrub height; comment by Locki 2026-04-06); no flick Z-dip; raises an error until measured or if not homed.

Variables to fill, all `(verify on bench)`, measured at Steps 13.44/13.47: `brush_x_min`, `brush_x_max` (bristle
edges, nozzle X), `edge_y` (nozzle tip over the plate's rear edge, at the brush X), `z_scrub` (Z where paper drags on
the bristle tops, minus 0.5). Nothing else is machine-specific.

Where in printer.cfg: after `[gcode_macro PRINT_END]` (LDO cfg l.629), before `[gcode_macro CHOME]`; above the
`SAVE_CONFIG` block in any case. The manual instruction lives in Ch 13 (Step 13.48), not Ch 12: Ch 12 runs before the
parts exist. Ch 12 Step 12.36 can carry a one-line forward note (non-step text).

PRINT_START (Ch 12 12.36 skeleton) insert after `QUAD_GANTRY_LEVEL`, above the existing `G28 Z`:

```ini
    G28 Z                                  ; provisional Z0 after QGL, tip not yet clean
    NOZZLE_PARK_BUCKET
    NOZZLE_CLEAN
```

Why two Z homes: after QGL the Z coordinate is off by the gantry correction until re-homed, so scrubbing at Z −0.45
needs a provisional home; the final `G28 Z` then touches the nozzle-probe pin with a clean tip (the point of the
add-on on a nozzle-probe Z0). The scrub runs at the QGL temperature (150 °C, `M104 S150` before QGL). ~+1 min.

Test (`../../.venv/bin/python test_macros.py`, exit 0): placeholders refused; unhomed refused; for O = 6.5/5.5/4.5/
4.0/3.5 the circles stay in y0+1.5 … Y_max−0.5 (r 2.00/1.75/1.25/1.00/0.75) and inside the bristle X span; Z drops
on its own line; ends at Z5; O = 2.8 refused; the park macro lifts before moving. Not run on real Klipper; the
`G2/G3` full circle (end = start, `I` only) is the author's own construct.

## 5. Which plate/batch

**Recommended: an add-on print outside the plate system.** Commit the three STLs (+ README with attribution and
CC BY-NC-SA) under e.g. `slicer/stl/addons/scrubber-796563/`; print them in one go on the Core One+ with
`slicer/voron-coreone-asa.ini` on the smooth sheet, any time after B10 (or after kit day; the parts are not on
anyone's critical path). The 22 plates, B11, every run total and `check_docs.py` stay untouched. Ch 13 lists them
as `… ×1 — from the scrubber add-on print` (parts grammar `— from`); no backticked STL names, so lint check 3
(STL in no batch) does not apply. Black spare is ~587 g (plan); 38 g fits.

**B12 (B11 precedent) costs too much for 38 g.** B11 (061dfd5, 100+ files) hard-codes itself in: `slicer/plates.py`
(`run=`, entries), `build_plates.py` (`TOTAL_LABEL`, ini map), `estimates.csv` (`TOTAL B11` row), `check_docs.py`
§ 8 (page, README, plan §3/§9, 00-index regexes, diagram 11), `build_printables.py` (`_BATCH_PRINT_ORDER`, schedules,
ledgers), `build_tonight.py` (`whole("B11")`), `docs/javascripts/boards.js`, `draw_diagrams.py`, `bins.py` (new bin),
part thumbnails + `MANIFEST.csv`, plate 3MF/PNG/SVG, a print page, README tables, nav. A B12 needs each generalised to
"batches outside the run" first. Only worth it if Alex wants the scrubber on the plate board / Tonight.

## 6. Ch 13 steps

Full text: **`ch13-append.md`** (Part L, Steps 13.44–13.50). Verified on a scratch copy of the repo with the text
spliced in after 13.43 and the Hardware rows below: `lint_manual.py --budgets` 0 findings (raw-callout check
skipped, no mkdocs build per brief), `--strict-parts --chapters 13` 0/0, `hooks/mascot.py --self-test` passed,
`build_tonight.py --self-test` OK.

| Step | Title | Power / heat | Helper |
|---|---|---|---|
| 13.44 | Measure the probe height and the reach past the plate (gate: d ≥ 0.6, O ≥ 3.5) | on, cold | yes |
| 13.45 | Press the magnets and seat the wiper | bench | yes |
| 13.46 | Bolt both brackets to the bed extrusions (+ Pause ~25 min) | on, cold, toolhead parked | yes |
| 13.47 | Read the brush coordinates off the machine | on, cold | yes |
| 13.48 | Add the scrubber macros | on | – |
| 13.49 | Dry-run the scrub cold | on, cold | yes |
| 13.50 | Scrub inside `PRINT_START`, then shut down (+ Pause ~30 min) | **hot** → add `13.50` to `NO_MASCOT_STEPS["hot"]`; no Helper | – |

Placement: after Step 13.43's `---`, before `## What if`; Checkpoint 13, Common mistakes and `## Next` stay below.
Step 13.43 shuts the machine down, so 13.44 powers it on again; 13.50 ends with the commit + shutdown.

Other edits the orchestrator owns (non-step text): Ch 13 header — Time +~1 h, Sessions 11 → 13, Printed parts table
gets a non-backticked add-on row, Hardware table replaces "— none —" with `M3×8 SHCS | 6`, `M3 roll-in T-nut | 4`,
`6×3 mm neodymium magnet | 4`; optional Checkpoint 13 line "scrubber fitted, dry-run clean (if fitted)"; 00-index
Ch 13 hours → re-run `python3 scripts/draw_diagrams.py --only 11`; the chapter scope/intro sentence; the
`00-tonight.md` regeneration that the build does.

## 7. Open risks / bench items

1. **O at the brush X** (13.44): 4.0–5.5 mm expected, ≥ 3.5 required; a notched LDO plate edge would end the add-on.
2. **d, Omron face above the nozzle tip** (13.44): ≥ 0.6 mm for the low set; the stock set needs ≥ 1.7 mm.
3. Right bracket vs the LDO nozzle-probe collar/body (13.46); fallback: run without the stop bracket.
4. Sheet-stop heads vs the plate's rear arris and the magnet pad edge (0.45 mm overlap in the author's CAD).
5. Magnet press fit in Ø6.2 pockets (author's own profile carries `filament_shrink 99.3%` despite telling users to
   turn compensation off; one maker opened the holes 0.05 mm). Glue fallback.
6. Scrub quality at 150 °C on ASA; if strings survive, scrub at 170–180 °C then wait back to 150 before `G28 Z`
   (dobromyslov's two-temperature sequence).
7. Kit magnet count: 16 shipped, 8 Nevermore + 4 here = 12; a later Klicky build would need its own.
8. Bed leads and WAGO mount clear of the left extrusion top behind the plate.
9. Clone wiper is ~0.2 mm taller; 13.47 measures the real top, so only the d margin moves.
10. A loaded bed mesh extrapolates its edge value behind the plate if `NOZZLE_CLEAN` is run by hand mid-session
    (PRINT_START clears the mesh first).

## Side findings (outside this task, not acted on)

- Ch 13 What-if rows "Probe triggers too early … Probe mounted too high … Lower the probe" and "too late … too low …
  Raise it" look inverted: a lower Omron face triggers earlier (larger gap). Check before Ch 13 is used.
- Step 09.30 / 09 Checkpoint "pin in the plate's rear cut-out": no cut-out is visible on LDO's plate photo (§ 3a).

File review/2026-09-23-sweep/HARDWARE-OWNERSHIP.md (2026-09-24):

# Hardware ownership: where each kit unit is consumed

Wave 4 phase 3b (claude, 2026-09-24). Input for the content packets P1–P9 (WAVE4-PLAN § 6).
Machine-readable map: `scripts/data/hardware-ownership.yml`. Code: `scripts/parts.py` (check 7, `--ledger`), `scripts/lint_manual.py` (`--strict-parts`).
Evidence is the Voron manual page image (`docs/manual/assets/manual-pages/manual-pNNN.png`), the LDO 350 Rev D BOM (`scripts/data/ldo-350-bom.yml`), the LDO wiring guide, or the Clicky-Clack sources named per row. Never a reviewer's summary.

## The rule

1. A kit unit is consumed once: at the step that first mounts, fastens, presses, glues, solders or plugs it into the machine or a sub-assembly. That step lists it as a counted part.
2. Earlier steps (unpack, inspect, set a switch, strip jumpers, trim, tape, bag) list it `staged:`. Later steps (adjust, remove and refit, route, verify) list it `reused:`. Neither is summed.
3. A chapter's Hardware table counts that chapter's consumption. It may also carry a quantity bagged here for a later chapter, but only as a `carries:` entry in the map. The consuming chapter then writes `0: bagged at Step …` or leaves the row out.
4. `reused:` needs an earlier consumption of at least that count. `staged:` needs a later one. Ch 00 is inventory: none of its kit mentions are consumption.
5. Stock drawn on demand, cut stock, tools and conditional rows (`unreconciled:` in the map) are `consumable:` or `tool:` and never reconciled. Bag rows (one BOM line, several parts) are reconciled per chapter, but not against the BOM quantity.

## What the checks do now

**Per chapter (check 7).** Table total = the chapter's counted consumption, plus carries staged here, minus carries consumed here. Not summed:

- `staged:`, `reused:`, `tool:` and `consumable:` lines, and `— from` items.
- Inventory chapters.
- Unreconciled rows. Their table rows are skipped too.

**Across the manual (check 7, new kinds).**

- `double-count`: an owned row listed as fitted at a step the map does not name. The message says whether it should be `staged:` or `reused:`.
- `owner-missing`: a map step that does not list its quantity as fitted.
- `carry-unstaged` / `carry-unfitted`: a carry's staging or consuming step is wrong.
- `fake-reuse`: `reused:` with fewer units fitted before it.
- `staged-unfitted`: `staged:` with nothing fitted later.
- `over-bom`: running consumption of an unowned row passes the BOM quantity.
- `map-error`: the map names an unknown item or step.

**Check 6** adds `unreconciled-row` (write `consumable:`/`tool:`) and `staged-xref`.

**Commands.**

- Packet gate: `python3 scripts/lint_manual.py --strict-parts --chapters 05,06`. It exits 1 on any check 6/7 finding in those chapters only; the cross-chapter findings are filed under the chapter that holds the step. The default gate keeps 6/7 as WARN.
- Per-step evidence: `python3 scripts/parts.py --ledger 'Wago 221-415'`. It prints every mention of a BOM row in manual order, with its role, its count and the step's Source line, so equal totals cannot hide a wrong step.

## Cross-chapter ownership (the map, readable)

"Inv" = Ch 00 inventory step. Listed = Hardware tables that name it today.

| Item | Listed | Staged | Consumed at | Reused at | Evidence |
|---|---|---|---|---|---|
| MGN9H rail ×6 | 02 (4), 05 (2) | Inv 00.17; 02.05 | 02.06 ×1, 02.09 ×3, 05.11 ×1, 05.13 ×1 | — | Voron p.24–27, p.88 |
| MGN12H rail ×1 | 05 | Inv 00.17 | 05.33 | — | Voron p.101 |
| Nitehawk SB PCB | 08 | Inv 00.5 | 08.43 | — | Ch 08 table |
| SB fan adapter PCB | 08 | Inv 00.5 | 08.44 | 08.45 | Ch 08 table |
| USB adapter PCB | **09** | Inv 00.5 | **08.64** | 09.25 | Ch 09's own note: stack fitted at 08.64 |
| Leviathan brackets L/R | — | Inv 00.6 | 09.20 | 09.21 | LDO wiring guide |
| NH Adapter Mount | — | Inv 00.6 | 08.64 | 09.25 | Ch 08.64 |
| DIN clip ×4 | — | Inv 00.6 | 09.20 ×2, 09.25 ×1 | — | Ch 09 M2×10 row; 4th = spare (open) |
| CW2 chain anchor | — | Inv 00.6; 08.6 | 08.25 | 10.59 | Ch 08.25 |
| 2×3 splitter spacer ×2 | — | Inv 00.6 | 10.37, 10.47 | 11.18 | LDO wiring guide ("mount 3x2 splicing PCBs using the printed part") |
| LDO nozzle probe | — | Inv 00.6 | 09.27 | 09.30 | LDO build FAQ |
| Bed WAGO mount | — | Inv 00.6 | 09.34 | — | LDO wiring guide § bed WAGO mount |
| CW2 PCB spacer | — | Inv 00.6 | 08.43 | — | Ch 08.43 |
| Aluminium handle ×2 | 11 | Inv 00.7 | 11.60 | — | LDO extra |
| Revo HF hotend | 08 | Inv 00.3; 08.27 | 08.28 | 08.29 | Ch 08.28 (seated in the printhead) |
| DIN rails ×2 | 09 | Inv 00.3 | 09.5 | — | Voron p.29 |
| Leviathan | 09 | Inv 00.3; 09.19 | 09.21 | 10.3 | 09.19 strips jumpers on the loose board |
| PSU | 09, **10** | Inv 00.3; 09.14 | 09.15 | 09.16, 10.2 | 09.15 fits its DIN brackets |
| C13 cord | — | Inv 00.3; 09.35 | 10.23 | 12.11 | first plugged in at 10.23 |
| Deck panel | 02 | Inv 00.4; 02.12 | 02.13 | 09.4 | Voron p.28–29 |
| Bottom / back / side ×2 / top panels | — | Inv 00.4; 11.52, 11.56 | 11.21 / 11.55 / 11.57, 11.58 / 11.59 | — | Voron p.232–243 |
| PC door panels ×2 | — | Inv 00.4 | not used | — | Clicky-Clack replaces the doors (11.61) |
| Magnetic pad | 03 | Inv 00.4; 03.1 | 03.9 | 03.10 | Voron p.58 |
| Build plate | 03 | Inv 00.4; 03.1–03.8 | 03.14 | 03.15–03.18 | Voron p.60–61 |
| Flex plate | 03 | Inv 00.4; 03.1 | 03.20 | 13.42 | Ch 03.20 |
| AC inlet | 09, **10** | — | 09.11 | 10.5 | LDO wiring guide: Ch 10 is wiring only |
| WAGO 221-415 ×3 | 09, **10** | — | 09.13 | 10.7 | 10.7 itself: "populated and mounted at Step 09.13" |
| WAGO 221-412 ×2 | 09, **10** | — | 09.34 | — | LDO: "two WAGO terminals are snapped into the printed part" |
| 2×2 XH splicer | 09, **10** | — | 09.34 | 10.12 | LDO: "2x2 XH Splicer PCB is fastened using two M3x6 BHCS" |
| SSR + DIN bracket | 09, **10** | — | 09.17 | 09.18, 10.10 | Ch 09.17 |
| XY / Z endstop PCB | 09 | — | 09.32 / 09.28 | 10.33 / — | Voron p.164; Ch 09.28 |
| Pi 4B + heatsink | 09 | — | 09.22 | — | Ch 09.22 |
| 3×2 XH splicer ×2 | 10, **11** | — | 10.37 (LED), 10.47 (fans) | 11.18 | LDO: "two 6020 fans are joined using the 3x2 splicing PCB" |
| 60×60×20 fan ×2 | **11** | — | 10.47 (plugged) | 11.3, 11.11 | rule 1: first connected at 10.47. Open question 1 |
| Keystone CAT6 insert | **11** | — | 10.51 (plugged) | 11.10 | Ch 10.51 |
| 4.3" DSI display | — | 10.50 | 11.6 (run from 10.50) | 12.10 | 10.50 builds the module by running 11.5–11.6 |
| 5015 blower (toolhead) | 08 | 08.34 | 08.42 | — | Ch 08.42 |
| Drag chains 10×10 ×2 / 10×15 | 10 | — | 10.59, 10.60 / 10.62 | — | Voron p.197–203 |
| **Carry:** M3×30 SHCS ×2 | 05, **09** | 05.46 (bagged with the pod) | 09.33 | — | Voron p.164, checked on the page: 2× M3×30 through the pod |

Other cross-chapter fastener stacks, checked on the pages. None needs a map entry, only `reused:`.

- **p.29.** The four deck M5 T-nuts are consumed at 02.11, and 09.5 reuses them. Ch 09's table already says "0 new here".
- **p.90 + p.111.** The four M3 and four M5 rail-slot T-nuts are consumed at 05.14. At 06.7/06.8, the M3×30 and M5×30 (4 each on p.111) thread into them.
- **p.115.** Four M5×40 SHCS at 06.14/06.15. 06b.8 removes them and 06b.13 refits the same four, so 06b.13 is `reused:`.
- **p.67/p.71.** The front-idler M3×40 SHCS and M3 washers are consumed in Ch 04 (04.11, 04.18). Ch 07 only adjusts them (07.5).
- **p.91/93/95.** The upper-Z-clip M5×16 BHCS are consumed in Ch 05. 06.20 is `reused:`.

## Corrections for the content packets

Format: `step or table row: current → correct (evidence)`. Scope: ownership and table corrections.
The within-chapter count errors (per-unit counts in build-all-four steps, uncounted items, multi-item bullets) are listed by `--parts-report <ch>`. Fix them against the page images and use `--ledger` to check.

### P1: Ch 00, 00a, 01 (5)

1. 00.14: `KADRICK M3×H5 inserts ×7, one per pocket` → `M3×H5 heat-set insert ×7 — from KADRICK kit` (AGENTS.md ruling 2026-09-14; not kit stock).
2. 01.3: `1× M5 roll-in T-nut and 1× M3 roll-in T-nut (for the fit test — both go back in their bags)` → `tool: M5 roll-in T-nut, fit test, back in its bag` and `tool: M3 roll-in T-nut, fit test, back in its bag` (the step's own text).
3. Ch 01 table: `M3 T-nut, roll-in | 1` → delete. The only M3 T-nut in the chapter is 01.3's, and it goes back in the bag.
4. 01.6: `4× A extrusion (prepared, from Step 01.4)` → `reused: the four prepared A extrusions`. Today it is an over-BOM of 12 > 10. Sweep every A/B mention with `--ledger 470A` and `--ledger 530B`: count each extrusion once, at its first fastening, and make the rest `reused:`.
5. Ch 01 table: `Corner bracket | 4` is not an LDO 350 BOM row. Name the source (`— from …`) or the BOM item (open question 7).

### P2: Ch 02 (3, plus the per-unit counts)

1. 02.05: `MGN9H 400 mm rails ×4 (…)` → `staged: MGN9H 400 mm rail ×4` (owners 02.06/02.09).
2. 02.12: `deck panel` → `staged: deck panel`.
3. 02.15: `the four M5 T-nuts already in the bed extrusions. **No bolts and no DIN rails yet.**` → `reused: the four deck T-nuts`. The sentence moves to Do.
4. Twenty per-unit mismatches (build-all-four steps, G2-03) → step totals against p.30–47. This is within the chapter, so no map entry.

### P3: Ch 03, 04 (7)

1. 03.1: all three → `staged:` (build plate, magnetic pad, flex plate).
2. 03.2, 03.3, 03.7, 03.8: `build plate…` → `staged: build plate`. 03.14: `build plate assembly` → counted `build plate, magnet applied ×1` (owner 03.14; p.60–61).
3. 03.10: `Magnetic pad (applied), sharp craft knife` → `reused: the applied magnetic pad` and `tool: sharp craft knife`.
4. Ch 03 table: `M4×6 BHCS (bed PE) | 1` → `0: pre-fitted to the plate` (03.6 ⚠; 10.x only backs it out).
5. Ch 03 table: `M3×12 SHCS + M3 washer (thermal fuse) | 0` → delete. The fuse is pre-applied (03.5).
6. Ch 03 table: the build-plate name contains " + " (table-multi) → `Build plate, cast 5083, heatpad and 125 °C fuse pre-applied`.
7. 04.28: `a 6 mm belt offcut or a thin steel rule` → `tool: a 6 mm belt offcut or a thin steel rule`.

### P4: Ch 05 (8)

1. 05.1: `C extrusion ×2, D extrusion ×1, E extrusion ×1` → three `staged:` bullets. Today it is an over-BOM, E 2 > 1; they are fitted at 05.5 (E), 05.11/05.13 (C) and the D step.
2. 05.4: `M5 roll-in T-nut ×26, M3 roll-in T-nut ×≈32 (+ ~30 for the backers)` → `staged: M5 roll-in T-nut ×26` and `staged: M3 roll-in T-nut ×N` (exact). Today M5 counts 52 against a table of 26: the consuming steps are 05.5, 05.13, 05.14 and 05.36.
3. 05.12: `the ~10 M3×8 SHCS already started` → `reused:`.
4. 05.13: split into `C extrusion ×1`, `MGN9H 400 mm rail ×1` (owner), `M3 roll-in T-nut ×N` and `M3×8 SHCS ×N`.
5. 05.46: split into `staged: M3×30 SHCS ×2` (carry to 09.33, p.164), `staged: [a]_endstop_pod_D2F_switch ×1` and `staged: [a]_cable_cover ×1`.
6. Ch 05 table: `MGN9H rail + carriage` → `MGN9H 400 mm rail | 2`; `MGN12H rail + carriage` → `MGN12H 400 mm rail | 1` (table-multi).
7. Ch 05 table: `M3×30 SHCS | 2` → Qty `2: bagged with the endstop pod at 05.46, fitted at 09.33 (p.164)`.
8. Ch 05 table: `Titanium backer, Y/X` and `M3×8 FHCS (backers, Y)` → `— from Ti backer set`. The West3D set ships 22× M3×8 FHCS and 10× M3×6 FHCS, per the note under the table. `M3×6 FHCS (backers, X) | ~8` → `— from Ti backer set` too, or it double-counts against the kit's M3×6 FHCS. The `≈`/`~` quantities need numbers: count the rail holes (p.88, p.101).

### P5: Ch 06, 07 (7)

1. 06.8: `the remaining 3× belt, 3× lower clip, 3× block, 3× M3×30 SHCS, 3× M5×30 BHCS` → counted bullets, so that 06.7 + 06.8 = 4 M3×30 and 4 M5×30 (p.111).
2. 06.20: `the two M5×16 BHCS on top of this corner (already in place)` → `reused:` (Ch 05, p.91/93/95).
3. 06b.8: `the four M5×40 SHCS from step 06.14` → `reused: the four Z-joint M5×40 SHCS` (no step ref).
4. 06b.13: `M5×40 SHCS ×4` → `reused: the four Z-joint M5×40 SHCS`. These are the same bolts (p.115: 4 total, table 4).
5. Ch 06 table: `Rubber rail stopper | 4` → `— from the Z rails` (not a BOM row; they ship on the rails).
6. 07.5: `the two M3×40 SHCS + M3 washers already in the front idlers (Ch 04, p.67 and p.71)` → `reused: the two front-idler M3×40 SHCS and M3 washers`.
7. Ch 07 table: `M3×40 SHCS + M3 washer | 2 + 2` → delete. They are consumed and listed in Ch 04 (p.67, p.71).

### P6: Ch 08 (12)

1. 08.27: the Revo parts → `staged:` (it assembles the loose hotend). 08.28: `Revo assembly` → counted `E3D Revo HF hotend, assembled ×1` (owner).
2. 08.29: hotend mentions → `reused:`.
3. 08.34: `50×50×15 centrifugal fan (24 V) ×1, flush cutters, small flat file` → `staged: 5015 blower ×1`, `tool: flush cutters` and `tool: small flat file`. 08.42: add counted `50×50×15 centrifugal fan ×1` (owner).
4. 08.41: `hotend fan wires` → `reused: the hotend fan's leads` (fitted at 08.40).
5. 08.43: split into `Nitehawk-SB V2 toolboard ×1`, `CW2 PCB Spacer ×1` and `M3×8 SHCS ×2` (owner for both boards).
6. 08.6: the anchor → `staged:`. 08.25: split into `CW2 Chain Anchor Tilted ×1` (owner) and `M3×20 SHCS ×1`.
7. 08.45: `fan adapter PCB, magnifier` → `reused: the fan adapter PCB` and `tool: magnifier`.
8. 08.50, 08.63: the toolhead cable and probe lead → `reused:`. 08.60 is the counted plug-in. Ch 08 table: rename `Toolhead cable (combined USB + 24 V), XT30(2+2)` → `Toolhead cable, USB and 24 V, XT30(2+2)` (table-multi).
9. 08.33: `E0508 ferrules ×2` → `consumable: E0508 ferrule ×2, only if re-terminating`. VE0508 is spare stock: the LDO wiring guide uses E0508 only for an integrated-heater hotend. Ch 08 table: `Ferrule, E0508 | 2` → delete or a `consumable` note.
10. Ch 08 table: `PTFE 4 mm OD / 2 mm ID, 10 cm` → `PTFE tube, 4 mm OD, 2 mm ID, 10 cm` (the `/` trips table-multi).
11. Ch 08 table: add `USB Adapter PCB | 1` and `NH Adapter Mount | 1` (fitted at 08.64). `M3×10 SHCS | 3` and `Ring-lug ground wire…` are not LDO BOM rows: name the source or fix the size (open question 6).
12. Steps that fit table rows but do not count them:
    - MR85 ×2: 08.12, 08.14.
    - IDGA gear set.
    - M3×50 ×2: 08.62, a multi-item bullet.
    - Captive M3×6: 08.51.
    - 16 inserts: 08.3, 08.4, 08.6 … now parse as ×4/×4/×3 after the count fix.

    Count them in their steps.

### P7: Ch 09, 10 (21)

1. 09.4: `deck panel ×1 (already fitted in Ch 02)` → `reused: the deck panel`.
2. 09.5: split into `DIN rail ×2` (owner), `DIN rail plastic end cap ×4`, `M5×10 BHCS ×4` and `reused: the four deck T-nuts` (p.29).
3. 09.14: `Meanwell LRS-200-24 ×1` → `staged:`. 09.15: add counted `Meanwell LRS-200-24 PSU ×1` (owner). 09.16: → `reused:`.
4. 09.19: → `staged: LDO Leviathan mainboard ×1` and `tool: a small pot or bag for the jumpers`. 09.21: split into `LDO Leviathan mainboard ×1` (owner), `reused: the two bracket assemblies` and `M3×8 SHCS ×4`.
5. 09.22: split into `Raspberry Pi 4B ×1`, `Raspberry Pi heatsink ×1` and standoffs `— from …` (verify).
6. 09.23: `Raspberry Pi 3/4 HAT power adapter ×1` → add `— from <its box>` (open question 5). It has no BOM row and falsely matches the Pi.
7. 09.33: keep `M3×30 SHCS ×2` counted (the carry's consumption). The "bagged by Ch 05" prose moves to Do.
8. 09.35: → `consumable: VE0508 ferrule ×5`, `staged: C13 power cord ×1` and `tool: cable tags`. The ring terminal needs a source.
9. 09.36, 10.80: `VHB tape`/`VHB pad` → `consumable:`.
10. Ch 09 table: `M3×30 SHCS | 2` → `0: bagged with the pod at Step 05.46` (carry).
11. Ch 09 table: `Ferrule, VE0508 | 5 | fitted in Ch 10…` → delete. They are spares; Ch 10's own row says so.
12. Ch 09 table: the `SSR + bracket | 1 + 1`, `Pi 4B + heatsink + standoffs + HAT | 1 set`, `XY / Z / USB adapter / 2×2 splicer | 1 each` and `GT2 pulley + shaft + set screw | 1 each` rows → one row each.
    - USB adapter PCB moves to Ch 08.
    - The nozzle-probe row becomes `LDO Nozzle Probe, collar and shaft pre-fitted | 1` (BOM: `Shaft, for Nozzle Probe`), plus the set screw if it is bagged.
13. Ch 09 table: add `Leviathan Bracket Left | 1`, `Leviathan Bracket Right | 1`, `DIN Clip | 3`, `LDO Nozzle Probe | 1` and `Bed WAGO Mount | 1`. `M3×5×4 heat-set insert | 2+` → an exact total.
14. 10.2, 10.3, 10.5, 10.10, 10.12: → `reused:` (the PSU, the Leviathan, the inlet, the SSR and the bed breakout, all fitted in Ch 09).
15. 10.7: → `reused: the three WAGO 221-415 blocks`.
16. 10.33: split into `XY endstop cable ×1` and `reused: the XY endstop PCB`.
17. 10.50: the display and the module parts → `staged:` (fitted at 11.5–11.6, which run from here). The FFC ribbon needs a source (the display box).
18. 10.54, 10.65, 10.67: the umbilical → `reused:` (plugged in at 08.60).
19. 10.23: `C13 power cord ×1. No meter` → `C13 power cord ×1` (owner). "No meter" moves to Do.
20. 10.59, 10.60, 10.62: split so that each chain is a counted bullet (owners).
21. Ch 10 table:
    - **Delete**, fitted in Ch 09: the `AC inlet`, `Meanwell PSU`, `SSR + DIN bracket`, `WAGO 221-415`, `WAGO 221-412` and `2×2 XH splicer` rows. Or write `0: fitted Ch 09`.
    - **Delete**: `VE0508 ferrule | 5` (spares).
    - **Add**: `60×60×20 fan | 2`, `Keystone CAT6 insert | 1`, `C13 power cord | 1` and `2×3 Splitter Spacer | 2`.
    - **Split**: `M5×10 BHCS + M5 roll-in T-nut | 2 + 2` and its frame-PE row → `M5×10 BHCS | 3` and `M5 roll-in T-nut | 3`.
    - **Number**: `M3×6 FHCS (chain ends) | (verify on bench)` needs a quantity.
    - **Count in steps**: the 20 inserts (10.35 is a multi-item bullet).

### P8: Ch 11 (11)

1. 11.3, 11.11: `60×60×20 mm 24 V fan ×2` → `reused: the two bay fans` (plugged in at 10.47; open question 1).
2. 11.10: `Keystone CAT6 insert ×1 (supplied)` → `reused:`. 11.18: `3×2 XH splicer PCB ×1, its printed spacer` → `reused:`.
3. 11.6: the display counts here (owner). `M2.5×6 screws ×4` → `— from BTT screen packaging`; the table row gets the same.
4. 11.21: split out `bottom panel ×1` (owner).
5. 11.52 and 11.56: the panels → `staged:`. 11.55: `back panel assembly from 11.52–11.54` → counted `back panel ×1`. 11.57, 11.58: add `side panel, PC clear 483×503 ×1` each. 11.59: split out `top panel ×1`.
6. 11.27: `5015 fan ×2` → `staged:`. 11.32 counts the two Nevermore 5015s. 11.29, 11.31 → `reused:`; they also alias to the toolhead 5015 row, see the resolver list.
7. 11.34, 11.36: `6×3 mm neodymium magnets` → a count (the table claims 8; the LDO guide gives none: verify on bench).
8. 11.48: `6×3 mm magnets ×12` → `6×3 mm magnet ×12 — from Clicky-Clack door kit`. KB3D: *"the magnets that were provided in the hardware kit for the Door Kit"*. The mod BOM says 12, but 11.48's own Do places 4 + 4 + 1 + 1 = 10 (open question 3).
9. 11.44, 11.50, 11.62, 11.64 and the latch steps: the door-kit hardware → `— from Clicky-Clack door kit` (tanaes mod BOM: M5×16 BHCS ×4, M5×45 dowel ×4, M5×7×8 bushing ×6, M3×20 SHCS ×4, M3×8 SHCS ×12, M3×8 BHCS ×1, M3×5×4 insert ×1). The M3 roll-in T-nuts stay kit (KB3D). `the 480 × 500 × 3 mm clear acrylic door panel` → `Clicky-Clack door panel ×1 — from Clicky-Clack acrylic panel` (Fabreeko line item; not the kit's PC doors).
10. Ch 11 table:
    - **Delete**: the `60×60×20 fan`, `3×2 XH splicer PCB` and `Keystone CAT6 insert` rows (Ch 10 owns them).
    - **Magnets**: split into `6×3 mm magnet | N` (Nevermore, kit) and `6×3 mm magnet — from Clicky-Clack door kit | 12`. Today they total 20 against a BOM of 16.
    - **Door-kit rows**: the dowel, bushing, M3×20 ×4, M3×8 ×12, M3×8 BHCS, Clicky M5×16 ×4 and latch insert ×1 rows → `— from Clicky-Clack door kit`.
    - **Not BOM rows**: `M3×16 BHCS | 4` (Nevermore) → `— from Nevermore Micro V5 Parts bag` (verify).
11. Ch 11 table quantities:
    - `M3 hammerhead T-nut | 7 + 8 + 16 + 4` → `35: 7 back + 8 top + 16 side + 4 Z covers`.
    - `M3×8 SHCS | belt guards…` and `M3 heat-set insert | skirt segments` → numbers.

### P9: Ch 12, 13, 14 (5)

1. 12.10: → `**Parts:** none.` The prose moves to Do.
2. 12.11: `C13 power cord ×1` → `reused: the C13 cord`.
3. 13.42: `clean flex plate` → `reused: the flex plate`.
4. 14.24: `M3×8 SHCS ×2, M3 roll-in T-nut ×2` (nameplate) → counted. Add them to Ch 14's table, which says "none" today.
5. 14.6: `the four M5×40 Z joint SHCS (already fitted, light)` → `reused:`.

### Not content: resolver aliases (`scripts/kit_bom.py` ALIASES + the vendored YAML; owner 1A)

These produce false double counts that no content edit can clear:

- SSR `\bssr\b(?!.*\bbracket\b)` matches "SSR to Wago cable" and "SSR to MB cable" (10.11, 10.27). Proposed: `(?!.*\b(?:bracket|cable)\b)`.
- Pi `\braspberry pi\b…` matches "Raspberry Pi 3/4 HAT power adapter" (09.23). Proposed: exclude `\bhat\b`.
- 5015 `\b5015\b(?!.*nevermore)` matches Nevermore fans on lines without the word (11.29, 11.31).

## Open questions

1. Bay fans: rule 1 puts consumption at 10.47 (first plugged in), so Ch 10's table owns them. If Alex prefers "physically mounted", flip the owner to 11.11 and move the table row back to Ch 11. It is a one-line map change.
2. The 4th DIN clip: a spare, or does a step use it?
3. Clicky-Clack magnets: 12 (mod BOM) against 10 (11.48's Do). Does LDO's door hardware kit also carry the M5×16, M3×20 and M3×8 screws? KB3D states only the magnets explicitly. (verify on bench)
4. Nevermore magnet count (8 in the table) is unverified.
5. Sources of the Pi HAT power adapter, the Leviathan standoffs and the FFC ribbon.
6. `M3×10 SHCS` (Ch 08, USB adapter stack), `M3×16 BHCS` (Nevermore) and the Ch 08 ring-lug wire are not LDO 350 BOM rows.
7. Ch 01 `Corner bracket` is not an LDO 350 BOM row.
8. Phase 3a converted `**Parts:** none — reason` into a `- none — reason` bullet (00a.8, 13.1, 13.2, 13.24, 13.34 …). Check 6 flags each one twice. They should go back to `**Parts:** none.`, with the reason in Do.

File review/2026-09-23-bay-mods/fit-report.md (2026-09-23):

# Fit report: four Printables mods on the LDO Voron 2.4 350 Rev D+ (2026-09-23)

Analysis only. Nothing in the repo was touched. Figures and slices are next to this file.

| Mod | Verdict |
|---|---|
| 502306 cable duct (CMD) | **Use with changes.** Use straight pieces only: no bridges, no 90° bridges, no PSU_Bracket-4D. The middle run fits only if the front rail moves ~5 mm forward; otherwise keep PVC there. |
| 505838 AC covers | **Wire-box lid: use with changes. Half-bridge cover: skip.** The inserts are multi-material geometry with zero clearance and do not press-fit as modelled. |
| 502345 wire guides | **Mostly skip.** Two 2-wire guides for the loose earth leads. The 90° rail-earth guides only if the DIN-rail earthing decision says "run PE to the rail". |
| 450348 handle | **Skip.** The bolted foot clashes with every panel edge. The kit already ships two aluminium handlebars for the same strip. |

## Sources and method

- Bay geometry was measured on LDO's `S0General_Placement.jpg` (`docs/manual/assets/remote/09-electronics-bay/bay-general-placement.jpg`). The photo was resampled to printer millimetres with the origin at the frame centre (px 957, 1043) at 3.25 px/mm; +y is the printer rear, +x the printer right. It is a **350**: the LRS-200-24 measures 218 × 115 mm at that scale (datasheet 215 × 115). Frame x reads ±235 mm.
  - **Known anomaly:** frame y reads only ±222 mm. Every absolute position below therefore carries ±6 %. Fit calls rest on local gaps (edge to edge within a few cm), where the error is ±1.5 mm.
  - The DIN-rail-only photo (`din-rails-and-wire-ducts.jpg`) is a different shot with slightly different duct positions. I did not use it for positions.
- Heights come from the Voron 2.4r2 STEP (the 250 machine; the relations hold for a 350):
  - deck face at 0;
  - DIN rail top 7.5 mm;
  - PSU body 22.5–52.5 mm above the deck;
  - controller PCB about 27–29 mm above the deck. That figure is the **Octopus bracket**; LDO's supplied Leviathan brackets were not measured (unverified).
- CMD geometry comes from sections and ray casts of the STLs (trimesh). Print orientation matches the author's Bambu 3MF: ducts and the wire box are flipped (base down), covers and inlays go as-is.
- Panel sizes are from Ch 11 (LDO 350 BOM): side and back 483 × 503, top 483 × 483.
  - The 350 frame is 510 wide and deep (verified from the 470 horizontals).
  - I assumed 530 tall (the vertical length scales by 50 per size; unverified). That gives a **13.5 mm inset from every outer frame edge**. The Voron CAD 250 shows the same ~13 mm inset.

## 1. Cable ducts (502306)

### CMD profile (measured)

- Base footprint 20.1 mm wide.
- The walls bulge to **24.4 mm** at 12.5 mm height.
- The lid is 24.1 mm wide. Installed height with the lid is **26.4 mm**.
- The PVC duct it would replace is 20 × 25 mm.
- Pieces butt-join; there is no interlock. Straight lengths are 82 / 142 / 154 mm.
- Bridge tunnels are **7.50 mm** below the base plane and about 36 mm long. That is 8.5 mm over the deck with 1 mm VHB: 1.0 mm over a bare 7.5 mm rail.
  - The M5 BHCS heads sit inside the hat, below the flanges.
  - **Not needed:** LDO's rails stop about 318 mm long (apparent). Both side runs pass outboard of the rail ends, so no duct crosses a rail.

### Clearances in the LDO bay (apparent mm)

| Run | Neighbours | Gap for a 24.4 mm duct | Call |
|---|---|---|---|
| Front | Leviathan header row −108, front Z motors y ≤ −175 at \|x\| > 150 | ~27 mm to the board | fits |
| Middle | Leviathan PCB edge −14 ↔ PSU edge +11 (PSU body starts 22.5 mm up; the duct with lid is 26.4 mm, so it cannot go under the PSU; the PCB at ~27 mm plus solder pins cannot overhang it) | **25–26.5 mm available vs 24.4 needed** | **does not fit reliably** |
| Rear | SSR tab +101, circle hole +139…+152 (x +7…+22), WAGO mount front ~+200, inlet +222, rear Z mounts x < −150 / > +175 at y ≥ +174 | 17 mm behind the duct, 6 mm in front | fits |
| Left | rail ends −148, Pi ports −110, frame −235 | 15 mm to the rail ends | fits |
| Right | PSU right end ~+189…+195 (top surface magnified), USB adapter +115…+148, frame +235 | shift outboard to x +197…+221 → ~14 mm to the frame | fits |

- The rear wire opening, the deck supports and the skirt line are not reached:
  - no duct lies within 14 mm of the frame;
  - skirts sit outside the frame footprint;
  - the bay is 78 mm deep against a 26.4 mm duct.
- The bed WAGO mount is **above** the deck: bed L is run "down through the deck opening" (Ch 10.14), and no LDO bay photo shows it. So it is not in the duct plane.
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

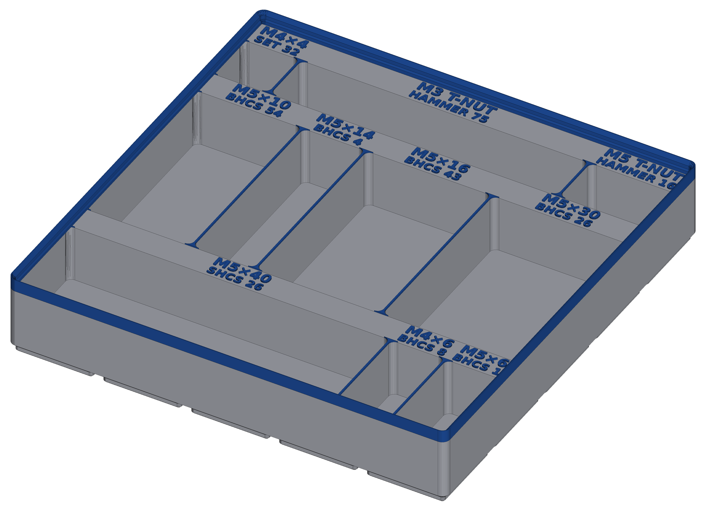
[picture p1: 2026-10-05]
slicer/bench/hardware-trays/renders/tray-B-34.png

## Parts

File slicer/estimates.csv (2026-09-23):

plate | batch | colour | parts | raw_time | hours | grams | prev_model_hours | prev_model_grams | delta_hours | delta_grams | brim_mm | size_kb
B00-P1 | B00 | black | 8 | 3h 57m 38s | 3.9606 | 51.66 | 3.5 | 57 | +0.46 | -5.3 | 0 | 337
B01-P1 | B01 | black | 7 | 15h 12m 35s | 15.2097 | 201.19 | 12.7 | 216 | +2.51 | -14.8 | 0 | 1469
B01-P2 | B01 | black | 16 | 7h 33m 52s | 7.5644 | 99.99 | 6.7 | 108 | +0.86 | -8.0 | 0 | 1653
B02-P1 | B02 | blue | 7 | 7h 0m 17s | 7.0047 | 90.03 | 5.9 | 100 | +1.10 | -10.0 | 0 | 2016
B02-P2 | B02 | blue | 13 | 7h 15m 6s | 7.2517 | 92.98 | 6.1 | 102 | +1.15 | -9.0 | 5 | 1049
B02-P3 | B02 | blue | 29 | 7h 33m 44s | 7.5622 | 95.58 | 6.5 | 106 | +1.06 | -10.4 | 0 | 2490
B03-P1 | B03 | black | 8 | 8h 29m 7s | 8.4853 | 118.97 | 7.7 | 130 | +0.79 | -11.0 | 0 | 1855
B04-P1 | B04 | black | 7 | 8h 33m 28s | 8.5578 | 116.63 | 7.3 | 122 | +1.26 | -5.4 | 0 | 1381
B05-P1 | B05 | black | 14 | 6h 21m 55s | 6.3653 | 78.01 | 5.2 | 83 | +1.17 | -5.0 | 0 | 2885
B06-P1 | B06 | black | 19 | 12h 8m 59s | 12.1497 | 147.73 | 9.8 | 162 | +2.35 | -14.3 | 0 | 4716
B07-P1 | B07 | black | 14 | 7h 51m 19s | 7.8553 | 101.92 | 5.7 | 96 | +2.16 | +5.9 | 3 | 596
B07-P2 | B07 | black | 8 | 8h 8m 57s | 8.1492 | 123.94 | 7.5 | 127 | +0.65 | -3.1 | 3 | 323
B08-P1 | B08 | black | 2 | 6h 16m 15s | 6.2708 | 99.22 | 6.1 | 105 | +0.17 | -5.8 | 3 | 305
B08-P2 | B08 | black | 3 | 8h 21m 7s | 8.3519 | 108.23 | 7.0 | 120 | +1.35 | -11.8 | 3 | 495
B08-P3 | B08 | black | 4 | 9h 31m 30s | 9.5250 | 121.87 | 8.0 | 136 | +1.53 | -14.1 | 3 | 615
B08-P4 | B08 | black | 2 | 4h 58m 35s | 4.9764 | 69.99 | 4.4 | 76 | +0.58 | -6.0 | 3 | 274
B09-P1 | B09 | black | 3 | 4h 32m 49s | 4.5469 | 62.80 | 4.1 | 71 | +0.45 | -8.2 | 3 | 1316
B09-P2 | B09 | black | 2 | 4h 55m 57s | 4.9325 | 67.37 | 4.3 | 73 | +0.63 | -5.6 | 3 | 2245
B09-P3 | B09 | black | 7 | 3h 54m 20s | 3.9056 | 54.60 | 3.5 | 60 | +0.41 | -5.4 | 3 | 750
B09-P4 | B09 | black | 21 | 4h 11m 30s | 4.1917 | 56.03 | 3.6 | 59 | +0.59 | -3.0 | 0 | 1226
B09-P5 | B09 | black | 16 | 4h 18m 53s | 4.3147 | 55.71 | 3.6 | 59 | +0.71 | -3.3 | 0 | 1104
B10-P1 | B10 | black | 8 | 5h 42m 57s | 5.7158 | 75.61 | 5.1 | 80 | +0.62 | -4.4 | 5 | 174
B11-P1 | B11 | petg | 2 | 26m 44s | 0.4456 | 4.04 |  |  |  |  | 0 | 20
B11-P2 | B11 | petg | 10 | 6h 53m 29s | 6.8914 | 96.44 |  |  |  |  | 0 | 469
B11-P3 | B11 | petg | 15 | 4h 36m 52s | 4.6144 | 73.31 |  |  |  |  | 0 | 416
B11-P4 | B11 | petg | 18 | 6h 18m 16s | 6.3044 | 82.28 |  |  |  |  | 0 | 311
B11-P5 | B11 | petg | 8 | 6h 50m 56s | 6.8489 | 93.02 |  |  |  |  | 0 | 466
TOTAL |  |  | 218 |  | 156.8472 | 2090.06 | 134.3 | 2248 | +22.55 | -157.9
TOTAL B11 |  |  | 53 |  | 25.1047 | 349.09

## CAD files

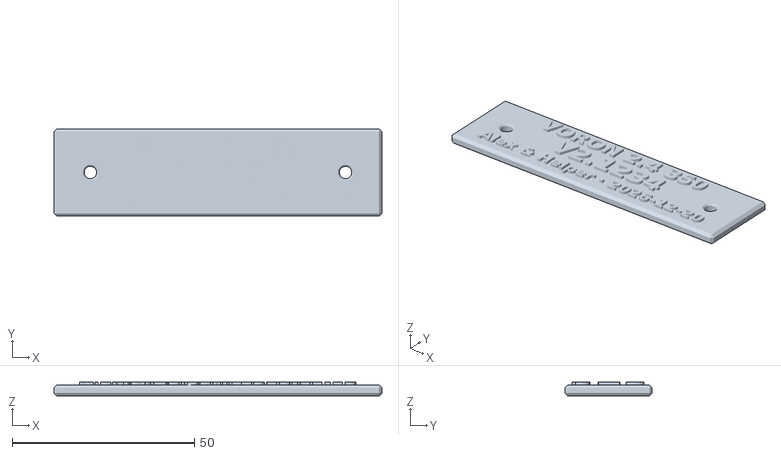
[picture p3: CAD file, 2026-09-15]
docs/manual/assets/nameplate/nameplate.stl
90.0 x 24.0 x 3.80

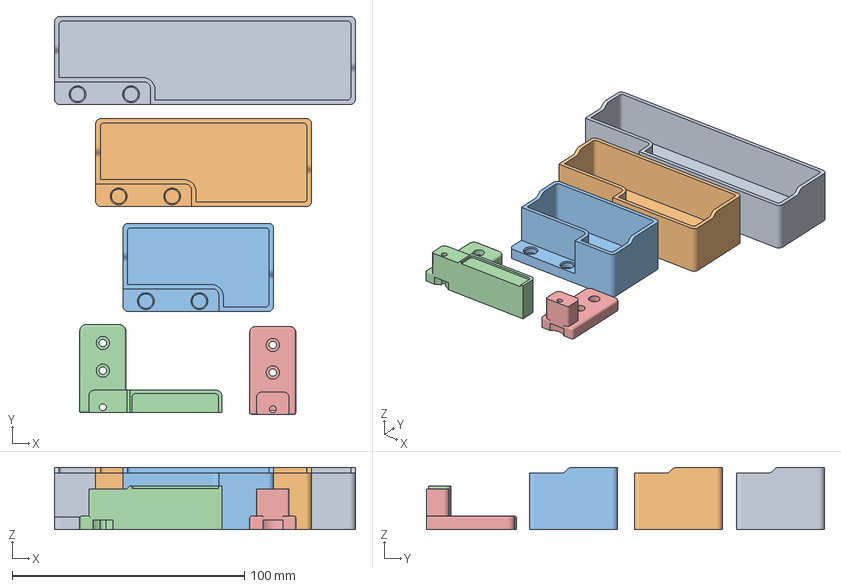
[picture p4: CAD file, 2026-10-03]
review/2026-10-03-scrubber/src/10mm Bed Setup.3mf
129.6 x 171.5 x 26.9 mm
0-SOLID-1
0-SOLID-2
0-SOLID-4
0-SOLID-3
0-SOLID-5

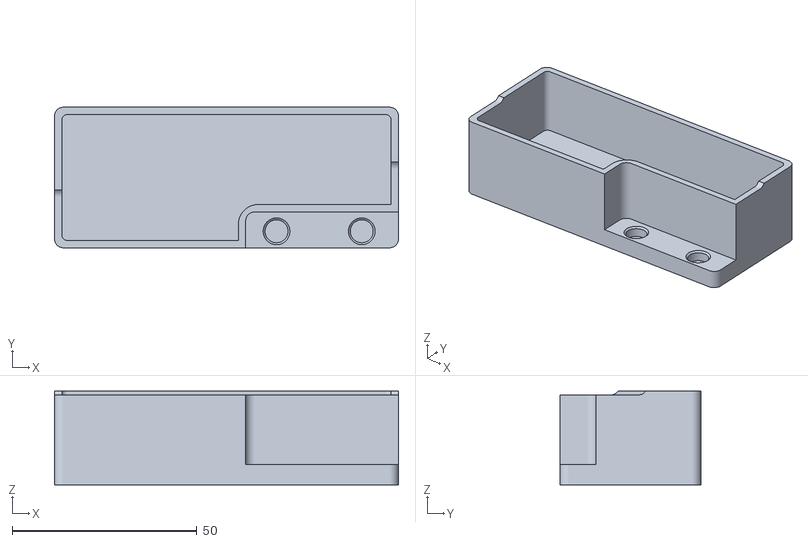
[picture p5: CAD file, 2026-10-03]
slicer/addons/scrubber-796563/bucket350_T1.5_MIRROR.stl
93.0 x 38.0 x 25.4

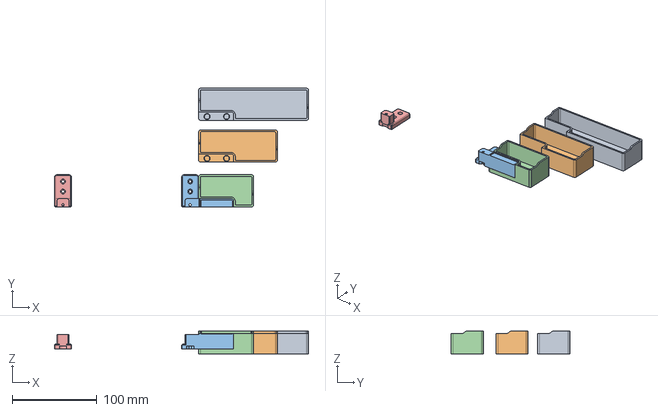
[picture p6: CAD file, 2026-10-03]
slicer/addons/scrubber-796563/source/10mm Bed.stp
299.6 x 140.1 x 26.9 mm

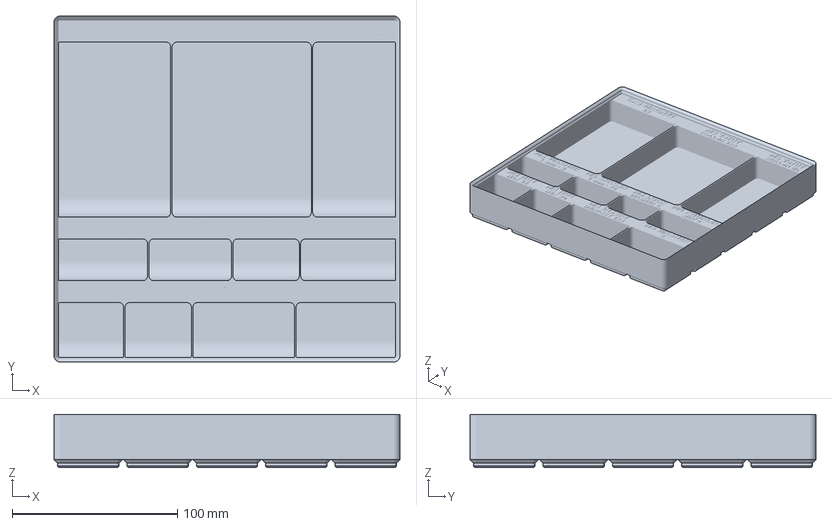
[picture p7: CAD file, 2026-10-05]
slicer/bench/hardware-trays/tray-C.3mf
209.5 x 209.5 x 32.1 mm

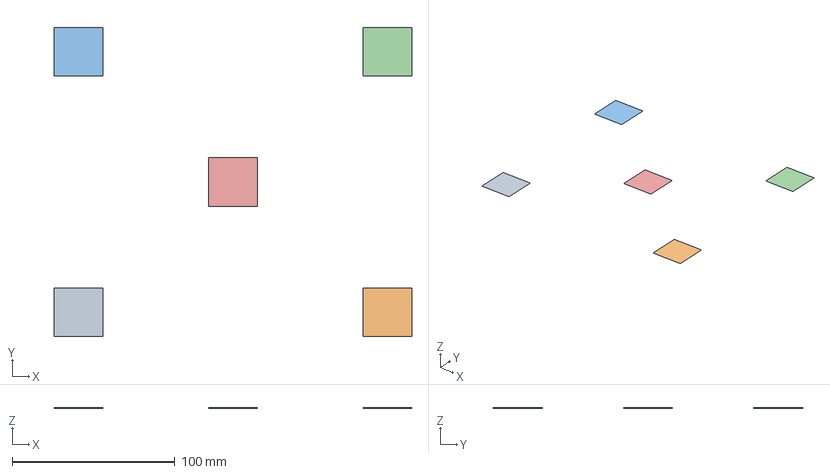
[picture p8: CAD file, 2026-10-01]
slicer/checks/hot-first-layer-heat-off.3mf
220.0 x 190.0 x 0.2 mm
square-front-left
square-front-right
square-back-left
square-back-right
square-centre

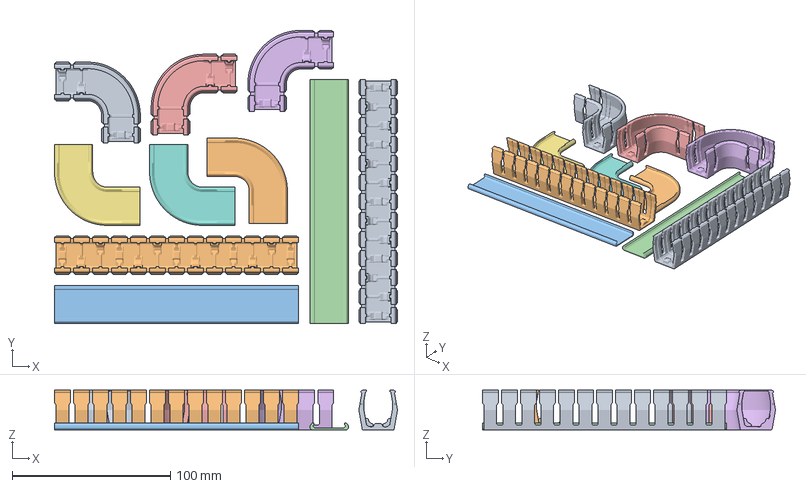
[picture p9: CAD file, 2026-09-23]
slicer/plates/B11-P2.3mf
216.5 x 185.0 x 25.0 mm
CMD_V3_1H_154mm_DUCT.stl#1
CMD_V3_1H_154mm_DUCT.stl#2
CMD_V2_6B_154mm_DUCT_COVER.stl#1
CMD_V2_6B_154mm_DUCT_COVER.stl#2
CMD_V3_1H_90DEG.stl#1
CMD_V3_1H_90DEG.stl#2
CMD_V2_6B_90DEG_COVER.stl#1
CMD_V2_6B_90DEG_COVER.stl#2
V2L_90DEG_MIRROR.stl
V2L_90DEG_COVER_MIRROR.stl

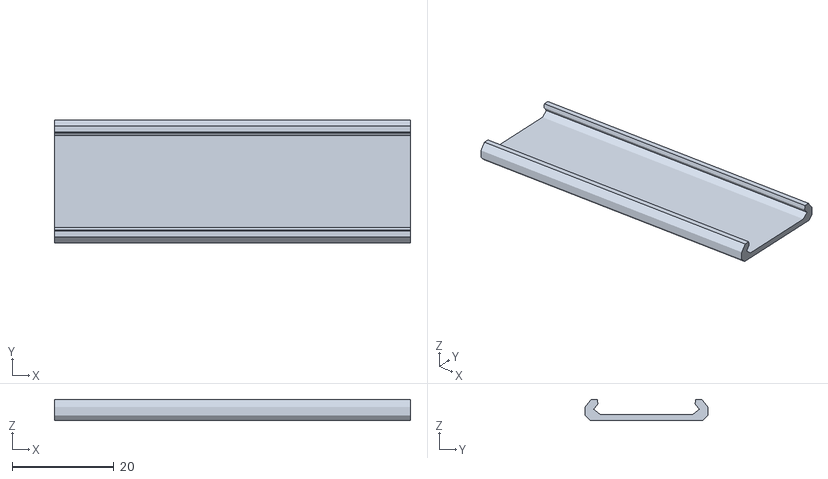
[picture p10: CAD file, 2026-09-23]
slicer/stl/bayducts/remix/V2L_70mm_DUCT_COVER.stl
70.0 x 24.1 x 4.20

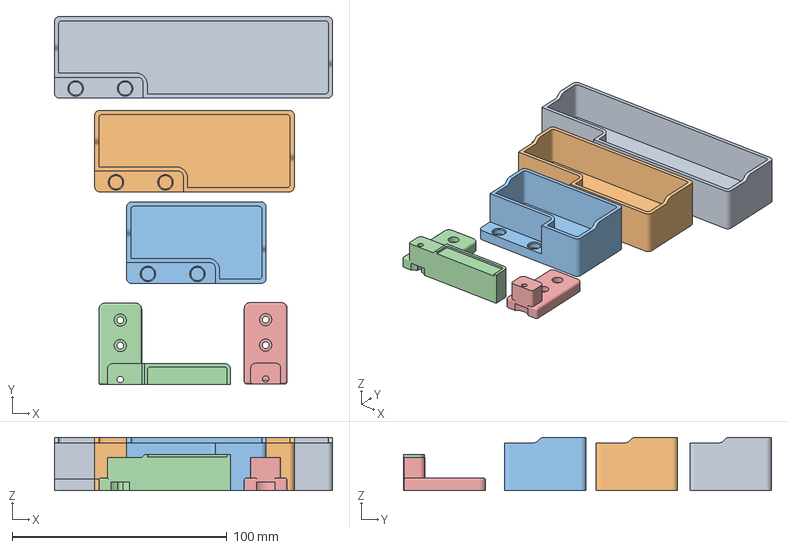
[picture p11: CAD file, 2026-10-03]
review/2026-10-03-scrubber/src/8mm Bed Setup.3mf
129.6 x 171.4 x 24.9 mm
0-SOLID-1
0-SOLID-2
0-SOLID-3
0-SOLID-4
0-SOLID-5

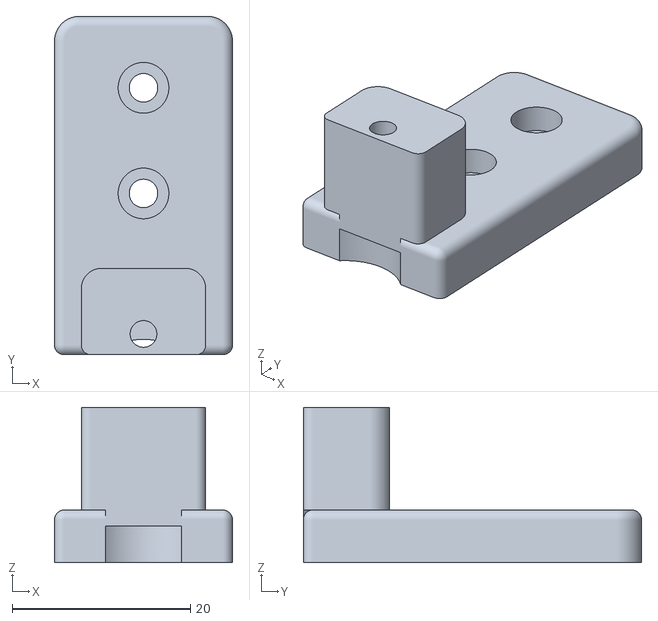
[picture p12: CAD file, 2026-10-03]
slicer/addons/scrubber-796563/stop_bracket.stl
20.0 x 38.0 x 17.5

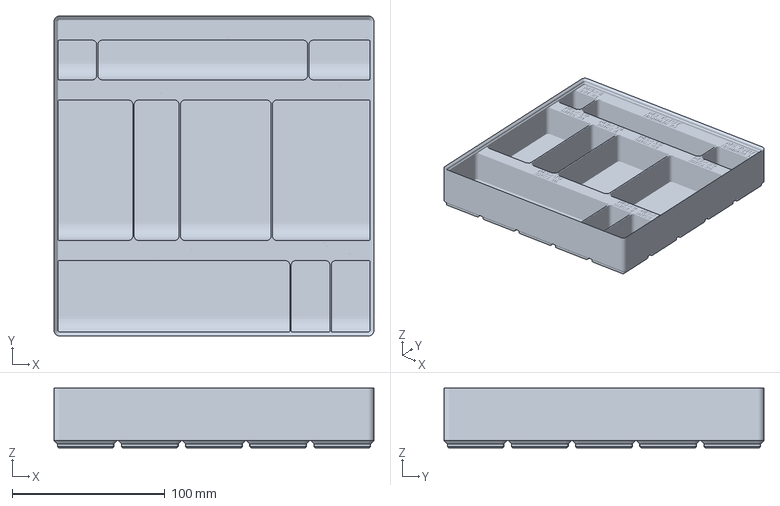
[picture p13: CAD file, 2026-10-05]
slicer/bench/hardware-trays/tray-B.3mf
209.5 x 209.5 x 39.1 mm

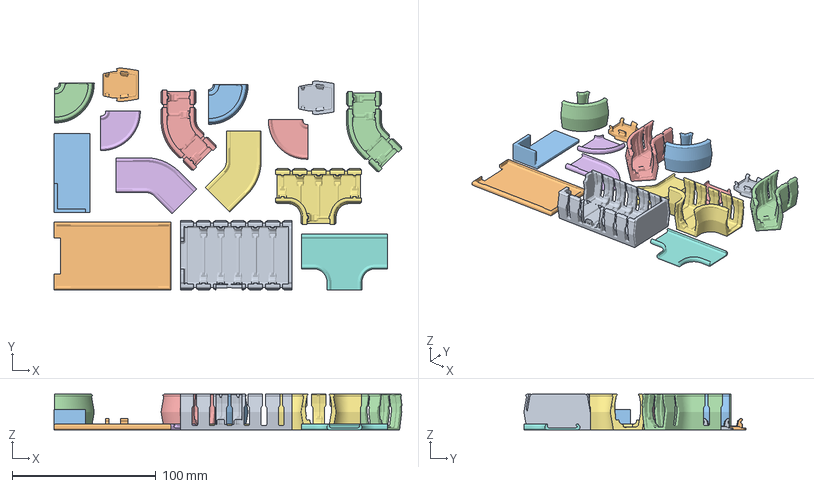
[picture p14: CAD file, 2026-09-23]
slicer/plates/B11-P3.3mf
242.0 x 154.5 x 25.0 mm
V3L_WIRE_BOX_PORT.stl
CMD_V2_6B_WIRE_BOX_COVER.stl
V3L_90DEG_R15.stl#1
V3L_90DEG_R15.stl#2
V3L_90DEG_R15_COVER.stl#1
V3L_90DEG_R15_COVER.stl#2
CMD_V3_1H_T_SHORT.stl
CMD_V2_6B_T_SHORT_COVER.stl
CMD_Remix-V3_DUCT-1M_ENDCAP.stl#1
CMD_Remix-V3_DUCT-1M_ENDCAP.stl#2
V2L_STRIP_FIN.stl
CMD_Remix-V3_DUCT-2B_45deg.stl#1
CMD_Remix-V3_DUCT-2B_45deg.stl#2
CMD_Remix-V3_DUCT-2B_45deg_LID.stl#1
CMD_Remix-V3_DUCT-2B_45deg_LID.stl#2

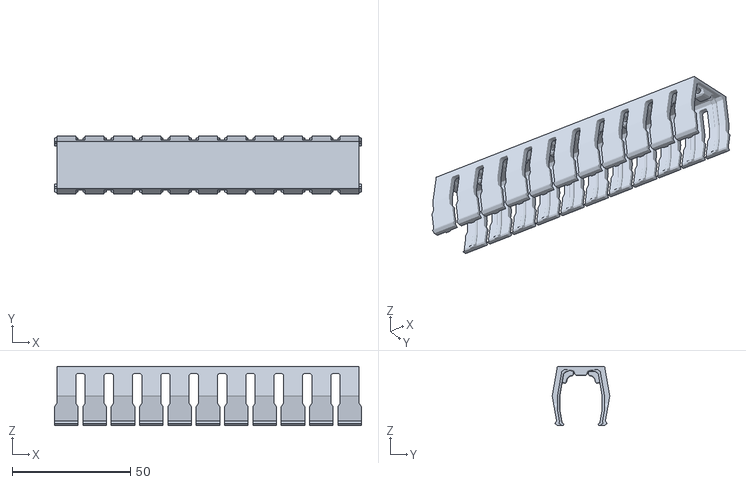
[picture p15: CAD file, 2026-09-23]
slicer/stl/bayducts/remix/V2L_130mm_DUCT.stl
130.0 x 24.4 x 25.0

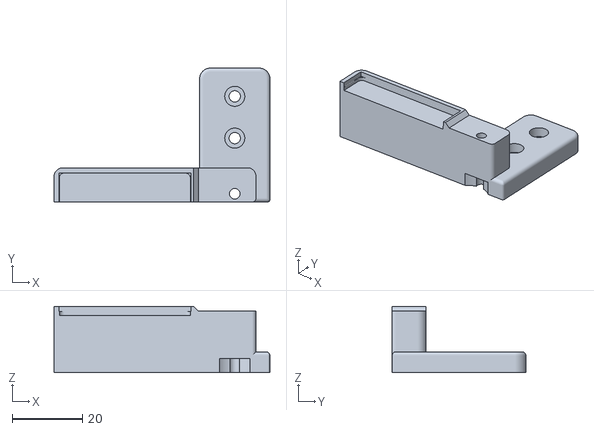
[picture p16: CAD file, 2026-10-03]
slicer/addons/scrubber-796563/brush_bracket_L1.5_MIRROR.stl
61.3 x 38.0 x 18.9

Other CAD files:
slicer/checks/hot-first-layer.3mf
slicer/bench/hardware-trays/tray-A.3mf
slicer/plates/B11-P4.3mf
slicer/stl/bayducts/remix/V3L_10mm_DUCT.stl
review/2026-09-23-bay-mods/layout-v2/remix/V2L_22mm_DUCT.stl
review/2026-09-23-bay-mods/layout-v2/remix/V2L_22mm_DUCT_COVER.stl
review/2026-09-23-bay-mods/layout-v2/remix/V2L_58mm_DUCT_HOLE.stl
review/2026-09-23-bay-mods/layout-v2/remix/V2L_AC_HUB.stl
review/2026-09-23-bay-mods/layout-v2/remix/V2L_AC_HUB_COVER.stl
slicer/bench/hardware-trays/tray-A.stl
slicer/bench/hardware-trays/tray-B.stl
slicer/bench/hardware-trays/tray-C.stl
slicer/plates/B00-P1.3mf
slicer/plates/B01-P1.3mf
slicer/plates/B01-P2.3mf
slicer/plates/B02-P1.3mf
slicer/plates/B02-P2.3mf
slicer/plates/B02-P3.3mf
slicer/plates/B03-P1.3mf
slicer/plates/B04-P1.3mf
slicer/plates/B05-P1.3mf
slicer/plates/B06-P1.3mf
slicer/plates/B07-P1.3mf
slicer/plates/B07-P2.3mf
slicer/plates/B08-P1.3mf
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

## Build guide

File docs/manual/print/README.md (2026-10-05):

# Print batches — overview

22 plates, **157.0 h**, **1813 g Galaxy Black + 279 g ASA Blue**. Every hour and gram on this page is a
**PrusaSlicer 2.9.6 estimate**, sliced from the committed project for that plate (`slicer/plates/*.3mf`) —
not a throughput model. Method and what these figures replaced:
[print plan §4.1](../../voron-print-plan.md#41-how-these-numbers-were-produced). Per-plate detail with the
previous figure beside each one, and the exact unrounded values, are in `slicer/estimates.csv`. Totals here are
sums of the rounded plate figures, so they can differ from that file's TOTAL rows by 0.1–0.2 h or a gram or two;
`python3 slicer/check_docs.py` re-checks every number on this page against it.

**B11**, the PETG V0 bay ducting, is a separate batch outside this run: 5 plates, 25.0 h, 348 g of Jet Black
PETG V0 on its own spool. None of its numbers are in the run's totals; it has its own table, run schedule
and ledger [at the end of this page](#b11-bay-ducting-petg-v0).

```mascot
pose: print
caption: Twenty two plates, start to finish. The printer works while the kit is still in transit.
```

**Print order.** The Voron kit is not expected before **late November 2026**, so the whole run goes down
first, in numeric batch order: pre-B00 checks on the current Gen 1 belts, then **B00 → B01 → B02 → … → B10**
— all 157.0 h, finished before the cartons land. **Gate A** (the cube, Step B00.5) releases the batches with no press fit;
**Gate B** (Step B00.7) releases the bearing-seat and bore batches and now runs *early*: the inserts come
from the KADRICK kit already on the bench and the bores are calipered against their STL nominals. Only the
bearing press and the MGN12 rail check wait for the kit, and the rail check gates nothing but a reprint of
the ASA `MGN12_rail_guide` (3 g, 20 min). The "print gate" column is the *print*
prerequisite; which assembly chapter consumes a batch is the "feeds" column, and the chapter-level
prerequisite lists live in [00-index.md](../00-index.md#chapters).

| batch | plates | hours | g black | g blue | feeds (assembly chapter) | print gate |
|---|---:|---:|---:|---:|---|---|
| [B00](B00-calibration-and-jigs.md) | 1 | 4.0 | 52 | 0 | Ch 00 (heat-set coupon, rail guides); Ch 02 / 05 (rail guides); Ch 04 (`pulley_jig`); B01 (one retainer) | — (it is the gate) |
| [B01](B01-z-drive-assemblies.md) | 2 | 22.8 | 301 | 0 | Ch 02 Z Drives and Idlers | **Gate B** (bore, inserts) |
| [B02](B02-accent-parts-orange.md) | 3 | 21.9 | 0 | 279 | accent for Ch 02, 04, 05, 06, 07, 08, 10, 11; `Handle` for B10 | Gate A |
| [B03](B03-ab-drive-units-and-front-idlers.md) | 1 | 8.5 | 119 | 0 | Ch 04 A/B Drives and Idlers | Gate B |
| [B04](B04-xy-joints-and-x-carriage.md) | 1 | 8.6 | 117 | 0 | Ch 05 Gantry | Gate B |
| [B05](B05-z-joints-and-z-chain.md) | 1 | 6.4 | 78 | 0 | Ch 06 Z joints; Ch 10 (chain anchor, guide) | Gate B |
| [B06](B06-toolhead-sb-cw2-klicky.md) | 1 | 12.1 | 148 | 0 | Ch 08 Stealthburner (Klicky set bagged, Ch 08.54) | Gate B |
| [B07](B07-electronics-bay-and-lighting.md) | 2 | 16.0 | 226 | 0 | Ch 09 Electronics bay; Ch 10 Wiring; Ch 11 (handlebar spacers) | Gate A |
| [B08](B08-skirts-and-front-modules.md) | 4 | 29.2 | 399 | 0 | Ch 11 Part A Skirts | Gate A — on Gen 1 GT2 belts, like every other plate in the run |
| [B09](B09-panels-filtration-spool.md) | 5 | 21.8 | 297 | 0 | Ch 11 Panels, Nevermore, spool | Gate A (after B08) |
| [B10](B10-clicky-clack-door.md) | 1 | 5.7 | 76 | 0 | Ch 11 Clicky-Clack door | Gate A (after B09) |
| **TOTAL** | **22** | **157.0** | **1813** | **279** | | |

All 22 diagrams on one page: [Plate plans](../../print/plate-plans.md).

**Filament margin:** Black 1813 g needed / 2400 g on hand → **587 g margin (32 %)**. Blue 279 g needed /
800 g on hand → **521 g margin (187 %)**. Setup and the full override table:
[00-slicer-setup.md](00-slicer-setup.md).

## Run schedule

All 22 plates in run order, at about two swaps a day: a plate of **7 h or more** starts in the evening and
runs overnight; anything shorter is a day plate, so two of them fit between breakfast and bedtime. The
longest plate in the build, B01-P1 at 15.2 h, is the exception — start it in the morning so its first layer
is watched, and let it run into the night. Spool column is the [ledger](#spool-ledger).

| # | plate | hours | colour | slot | spool |
|---:|---|---:|---|---|---|
| 1 | B00-P1 | 4.0 | black | day | #1 |
| 2 | B01-P1 | 15.2 | black | overnight (start in the morning) | #1 |
| 3 | B01-P2 | 7.6 | black | overnight | #1 |
| 4 | B02-P1 | 7.0 | blue | overnight | A1 |
| 5 | B02-P2 | 7.3 | blue | overnight | A1 |
| 6 | B02-P3 | 7.6 | blue | overnight | A1 |
| 7 | B03-P1 | 8.5 | black | overnight | #1 |
| 8 | B04-P1 | 8.6 | black | overnight | #1 |
| 9 | B05-P1 | 6.4 | black | day | #1 |
| 10 | B06-P1 | 12.1 | black | overnight | #2 (fresh) |
| 11 | B07-P1 | 7.9 | black | overnight | #2 |
| 12 | B07-P2 | 8.1 | black | overnight | #2 |
| 13 | B08-P1 | 6.3 | black | day | #2 |
| 14 | B08-P2 | 8.4 | black | overnight | #2 |
| 15 | B08-P3 | 9.5 | black | overnight | #2 |
| 16 | B08-P4 | 5.0 | black | day | #2 |
| 17 | B09-P1 | 4.5 | black | day | #2 → #3 |
| 18 | B09-P2 | 4.9 | black | day | #3 |
| 19 | B09-P3 | 3.9 | black | day | #3 |
| 20 | B09-P4 | 4.2 | black | day | #3 |
| 21 | B09-P5 | 4.3 | black | day | #3 |
| 22 | B10-P1 | 5.7 | black | day | #3 |

Twelve overnight plates and ten day plates, 157.0 h in all: about 16 printer-days, three to four weeks at
two swaps a day.

## Bins

Every printed part has **one bin**, keyed to the step that first opens it: a bin holds the parts first needed at one
point in the build, one step or one run of steps in a chapter. Ch 11 Part A and Part B are two points because
Ch 13 runs between them; B11's conduit bodies (Ch 09), AC lids (Ch 10) and DC lids (Ch 11) are three. A point is
split into sub-bins where it is part-heavy (the four Z corners, the A and B drive sides, the 4 mm and 6 mm panel clips). Parts staged early and carried
along (Steps 05.45, 05.46, 06.26), and jigs taken out and put back (`00-jigs`), stay in one bin. The bin id is what
you write on the part and on the box; the plate diagram at the top of every Load step shows each part
numbered and filled in its bin's colour with the id on it, and each batch's *Sort into bins* step lists
bin → parts per plate.

**Mark the plate too.** As a plate is sorted, write its plate id and the date beside the bin id, on a
face that will not show once the part is fitted, with a fine paint marker — `B03-P1 2026-09-20`. A
reprinted part gets the new plate id with an **R** after it, plus the extrusion multiplier if that changed
— `B03-P1R 94.5%`. The [run schedule](#run-schedule) and the [spool ledger](#spool-ledger) are the lookup:
plate id → date, spool and slicer settings, so a part that fits badly next year can be traced to the run
that made it, and one bad run can be reprinted without guessing which parts came off it. The scheme lives in `slicer/bins.py` (the diagrams, the `bin` column in
`docs/manual/assets/parts/MANIFEST.csv`, the [bin labels](../../print/bin-labels.md) and their [bag and box index](../../print/bin-labels.md#bin-map) are all
generated from it); `python3 slicer/check_docs.py` cross-checks this table, the batch chapters and the
manifest against it. Z corner map (Ch 02 Step 02.02): `_a` parts build Z0 (front-left) and Z2 (rear-right),
`_b` parts build Z1 (rear-left) and Z3 (front-right); a `_x2` file with an `_a` / `_b` hand puts one copy in
each of its two corners, a `_x4` file one in each corner.

33 bins, 279 printed pieces: 218 from the ASA run, 53 from B11 and 8 from the two add-ons, which print
after kit day and are on no plate (`13-scrubber`, `14-exhaust`). They travel in 29 of 48 A5 and 6 of 12 B5
mesh bags, plus 1 box. The A5 figure counts one more pack of A5 bags, 24 to a pack, still to buy
(Ch 00 Step 00.11). Two kinds of entry count toward no piece total: B11's fallback middle joints, printed only
instead of B11-P5, and the add-ons' bought parts (A1 wipers, exhaust fan, lead and carbon mat), kept in their bins.

**Bag per bin** (the *bag* column), measured from the STLs by `python3 slicer/bin_bags.py`: a bag's
usable inside is its paper size (A5 148 × 210 mm, B5 176 × 250 mm) and about 25 mm deep, an
assumption; a thicker piece still fits if each millimetre over 25 comes off both flat sides. Pieces
lie on a flat face, and a bag holds a bin when every piece fits and their bounding boxes add up to no
more than half the bag's volume. A bin takes one A5 if it can, else one B5, else two or three bags; a
bin needing more goes in a box (`11-skirts`, the skirt ring). A bin in several bags has all of them opened at
the same step; `09-ducts-DC` (three A5) and `14-exhaust` (two B5) are split by size, and `bin_bags.py --check`
tests every bag of a split on its own. A bin with fallback parts is sized for the worse of its two cases, and a
bought part is packed at a nominal size. Every label prints at half US Letter
and trims to fit inside an A5 bag, so a bag label reads through the mesh and a box label tapes on.

| bin | label | chapter · steps | bag | parts (qty) | from batches |
|---|---|---|---|---|---|
| **00-jigs** | Jigs and coupons | Ch 00 · 00.14–00.22 (rail guides again at 02.06, 05.11, 05.33; pulley jig at 04.24, 04.33; cube at 14.11) | A5 | `Voron_Design_Cube_v7`, `Heatset_Practice`, `MGN12_rail_guide` ×2, `MGN9_rail_guide` ×2, `pulley_jig` | B00 |
| **02-Z0** | Z0 corner (front-left, `_a` hand) | Ch 02 · 02.01–02.44 (drive 02.17–02.38, idler 02.39–02.43) | A5 | `z_drive_retainer_a`, `z_drive_main_a`, `z_motor_mount_a`, `z_tensioner_bracket_a`, `[a]_z_drive_baseplate_a`, `[a]_belt_tensioner_a`, `[a]_z_tensioner_9mm`, `z_rail_stop` | B00, B01, B02, B05 |
| **02-Z1** | Z1 corner (rear-left, `_b` hand) | Ch 02 · 02.01–02.44 (drive 02.17–02.38, idler 02.39–02.43) | A5 | `z_drive_main_b`, `z_drive_retainer_b`, `z_motor_mount_b`, `z_tensioner_bracket_b`, `[a]_z_drive_baseplate_b`, `[a]_belt_tensioner_b`, `[a]_z_tensioner_9mm`, `z_rail_stop` | B01, B02, B05 |
| **02-Z2** | Z2 corner (rear-right, `_a` hand) | Ch 02 · 02.01–02.44 (drive 02.17–02.38, idler 02.39–02.43) | A5 | `z_drive_main_a`, `z_drive_retainer_a`, `z_motor_mount_a`, `z_tensioner_bracket_a`, `[a]_z_drive_baseplate_a`, `[a]_belt_tensioner_a`, `[a]_z_tensioner_9mm`, `z_rail_stop` | B01, B02, B05 |
| **02-Z3** | Z3 corner (front-right, `_b` hand) | Ch 02 · 02.01–02.44 (drive 02.17–02.38, idler 02.39–02.43) | A5 | `z_drive_main_b`, `z_drive_retainer_b`, `z_motor_mount_b`, `z_tensioner_bracket_b`, `[a]_z_drive_baseplate_b`, `[a]_belt_tensioner_b`, `[a]_z_tensioner_9mm`, `z_rail_stop` | B01, B02, B05 |
| **02-deck** | Deck panel clips | Ch 02 · 02.11–02.15 (confirm thickness at 02.12) | A5 | `deck_support_3mm` ×8 | B01 |
| **04-A** | A drive unit + A (right) front idler | Ch 04 · 04.1–04.24 (A idler 04.6–04.9, A drive 04.20–04.24) | A5 | `[a]_tensioner_right`, `a_drive_frame_lower`, `a_drive_frame_upper`, `front_idler_right_lower`, `front_idler_right_upper` | B02, B03 |
| **04-B** | B drive unit + B (left) front idler | Ch 04 · 04.1–04.33 (B idler 04.13–04.16, B drive 04.29–04.33) | A5 | `[a]_tensioner_left`, `b_drive_frame_lower`, `b_drive_frame_upper`, `front_idler_left_lower`, `front_idler_left_upper` | B02, B03 |
| **05-XY** | XY joints, endstop pod, upper Z belt clips | Ch 05 · 05.3–05.38 (upper Z belt clips 05.19–05.23; endstop pod bagged at 05.46, fitted at 09.32–09.33) | B5 | `[a]_endstop_pod_D2F_switch`, `[a]_xy_joint_cable_bridge_2hole`, `XY_cable_chain_bridge-Igus-3mm_backer`, `[a]_z_belt_clip_upper` ×4, `xy_joint_left_lower_MGN12`, `xy_joint_left_upper_MGN12`, `xy_joint_right_lower_MGN12`, `xy_joint_right_upper_MGN12` | B02, B04 |
| **06-Z-joints** | Z joints and lower Z belt clips | Ch 06 · 06.3–06.9 | A5 | `[a]_z_belt_clip_lower` ×4, `z_joint_lower` ×4, `z_joint_upper` ×4 | B02, B05 |
| **07-X** | X carriage halves, probe bracket, cable cover | Ch 07 · 07.6–07.39 (staged at 05.45; probe 07.35; cover 07.39) | A5 | `[a]_cable_cover`, `x_frame_V2TR_MGN12_left`, `x_frame_V2TR_MGN12_right`, `probe_retainer_bracket` | B02, B04 |
| **08-SB** | Stealthburner body, printhead, LEDs | Ch 08 · 08.2–08.62 (printhead 08.28–08.30, LEDs 08.35–08.37, body 08.62) | B5 | `[a]_stealthburner_main_body`, `stealthburner_printhead_revo_voron_front`, `stealthburner_printhead_revo_voron_rear_cw2`, `[o]_stealthburner_LED_carrier`, `[o]_stealthburner_LED_diffuser_mask` | B02, B06 |
| **08-CW2** | Clockwork 2 extruder, toolboard + USB covers | Ch 08 · 08.3–08.20 (toolboard cover 08.51, USB adapter cover 08.64) | A5 | `[a]_guidler_a`, `[a]_guidler_b`, `[a]_latch`, `[a]_latch_shuttle`, `main_body`, `motor_plate`, `cw2_captive_pcb_cover`, `usb_adapter_mount_partial_cover` | B02, B06, B07 |
| **09-bay** | Electronics bay: inlet, WAGO, PSU, DIN clips | Ch 09 · 09.7–09.16 (inlet 09.10–09.12, WAGO 09.13, PSU 09.15–09.16) | A5 | `wago_221-415_mount_3by5`, `lrs_200_psu_bracket` ×2, `PSU_stabilizer_50mm`, `pcb_din_clip` ×3, `power_inlet_IECGS_1mm` | B07 |
| **09-ducts-DC** | DC conduit + coupon, B11 | Ch 09 · 09.6 (dry-laid at B11.10, stuck down at 09.36; coupon tested at B11.4 and B11.10) | A5 ×3 | `V3L_COUPON_22N_DUCT`, `V3L_COUPON_22N_DUCT_COVER`, `CMD_V3_1H_154mm_DUCT` ×2, `CMD_V3_1H_90DEG` ×2, `V2L_90DEG_MIRROR`, `CMD_Remix-V3_DUCT-2B_45deg` ×2, `V2L_58mm_DUCT` ×3, `V2L_130mm_DUCT`, `V2L_70mm_DUCT`, `V3L_10mm_DUCT`, `V3L_154N_DUCT` ×2, `V3L_T_REG_N` ×2; fallback, if gap < 25 mm: `CMD_V3_1H_T_REG` ×2, `CMD_V3_1H_82mm_DUCT` | B11 |
| **09-ducts-AC** | AC conduit, B11 | Ch 09 · 09.36 (dry-laid at B11.10) | A5 | `V3L_WIRE_BOX_PORT`, `V3L_90DEG_R15` ×2, `CMD_V3_1H_T_SHORT`, `CMD_Remix-V3_DUCT-1M_ENDCAP` ×2, `V3L_10mm_DUCT` ×2, `V3L_34mm_DUCT_HOLE` | B11 |
| **10-chains** | Z cable chain anchor, guide, retainer | Ch 10 · 10.35, 10.62–10.64 (bagged with the chain at 06.26; inserts 10.35) | A5 | `[a]_z_chain_retainer_bracket` ×2, `z_chain_bottom_anchor`, `z_chain_guide` | B02, B05 |
| **10-lights** | COB light-strip mounts | Ch 10 · 10.35–10.36 | A5 | `cob_light_strip_mount_100mm` ×6, `cob_light_strip_mount_50mm` ×2 | B07 |
| **10-tft** | Touchscreen faceplate + mount | Ch 10 · 10.50 (builds the module: Ch 11 Steps 11.5–11.6) | B5 | `[a]_faceplate`, `mount` | B02, B08 |
| **10-lids-AC** | AC lids + strip fin, B11 | Ch 10 · 10.80 | A5 | `CMD_V2_6B_WIRE_BOX_COVER`, `V3L_90DEG_R15_COVER` ×2, `CMD_V2_6B_T_SHORT_COVER`, `V2L_STRIP_FIN`, `V3L_10mm_DUCT_COVER` ×2, `V3L_34mm_DUCT_COVER` | B11 |
| **11-skirts** | Skirt ring, keystone panel and inserts | Ch 11 · 11.1–11.19 (keystone 11.10, bestagon 11.19) | box | `[a]_keystone_blank_insert` ×2, `ldo_bestagon_insert`, `rear_center_skirt_350`, `side_fan_support` ×2, `front_skirt_a_350`, `front_skirt_b_350`, `side_skirt_a_350` ×2, `side_skirt_b_350` ×2, `keystone_panel` | B02, B08 |
| **11-fans** | Fan grills, retainers, belt guards | Ch 11 · 11.3, 11.9, 11.11, 11.16 | A5 | `[a]_fan_grill_a` ×2, `[a]_fan_grill_b` ×2, `[a]_fan_grill_retainer` ×2, `[a]_belt_guard_a` ×2, `[a]_belt_guard_b` ×2 | B02 |
| **11-panels** | Bottom-panel clips/hinges, Z belt covers | Ch 11 · 11.20–11.25 | A5 | `z_belt_cover_a` ×2, `z_belt_cover_b` ×2, `bottom_panel_hinge` ×2, `bottom_panel_clip` ×4 | B09 |
| **11-lids-DC** | DC lids, B11 | Ch 11 · 11.52 | A5 | `CMD_V2_6B_154mm_DUCT_COVER` ×2, `CMD_V2_6B_90DEG_COVER` ×2, `V2L_90DEG_COVER_MIRROR`, `CMD_Remix-V3_DUCT-2B_45deg_LID` ×2, `V2L_58mm_DUCT_COVER` ×3, `V2L_130mm_DUCT_COVER`, `V2L_70mm_DUCT_COVER`, `V3L_10mm_DUCT_COVER`, `V3L_154N_DUCT_COVER` ×2, `V3L_T_REG_N_COVER` ×2; fallback, if gap < 25 mm: `CMD_V2_6B_T_REG_COVER` ×2, `CMD_V2_6B_82mm_DUCT_COVER` | B11 |
| **11-clips-4mm** | Panel clips, 4 mm (back + top panels) | Ch 11 · 11.53, 11.59 | A5 | `corner_panel_clip_4mm` ×8, `midspan_panel_clip_4mm` ×7 | B09 |
| **11-finish** | Exhaust cover + grill, handlebar spacers | Ch 11 · 11.54, 11.60 | A5 | `handlebar_spacer` ×4, `exhaust_cover`, `exhaust_filter_grill` | B07, B09 |
| **11-clips-6mm** | Panel clips, 6 mm (side panels) | Ch 11 · 11.57–11.58 | A5 | `corner_panel_clip_6mm` ×8, `midspan_panel_clip_6mm` ×8 | B09 |
| **11-nevermore** | Nevermore plenum + cartridge | Ch 11 · 11.26–11.40 | B5 | `V2_Duo_Plenum`, `V2_Duo_Plenum_LID`, `Regular_Cartridge_Lid(contributed_by_Bucknova)`, `Regular_Cartridge(contributed_by_Bucknova)` | B09 |
| **11-spool** | Spool holder + bowden retainer | Ch 11 · 11.42–11.43 | A5 | `spool_holder`, `bowden_retainer` | B09 |
| **11-door** | Clicky-Clack door | Ch 11 · 11.44–11.50, 11.62–11.64 | A5 | `Handle`, `Handle-Hinge_Bottom`, `Handle-Hinge_Top`, `Hinge-L-sleeve-2X` ×2, `Hinge-L-solid-2X` ×2, `Latch`, `Panel_Clip` | B02, B10 |
| **13-scrubber** | Nozzle scrubber add-on: brackets + bucket | Ch 13 · 13.44–13.54, Part L (printed 13.48, fitted 13.49–13.50) | A5 | brush bracket, stop bracket, purge bucket (file names from `measured/`, Step 13.47); bought: Bambu A1 nozzle wiper ×3 | add-on, on no plate |
| **14-exhaust** | Chamber exhaust add-on: housing, grill, cover, mounts | Ch 14 · 14.25–14.36, Part H (printed 14.26, built 14.27–14.29) | B5 ×2 | `exhaust_filter_housing`, `[a]_exhaust_fan_grill`, `[a]_filter_access_cover`, `[a]_exhaust_filter_mount` ×2; bought: 24 V 6020 fan; 1 m JST-XH 2-pin extension lead; carbon-mat piece ×2 | add-on, on no plate |
| **spare-alt** | Spares / alternates (not fitted) | — · not fitted (Klicky set bagged at 08.54) | A5 | `[a]_pcb_spacer`, `KlickyProbe_v2` ×2, `Probe_Dock_v2.1`, `Probe_magnet_holder`, `Probe_magnet_pressfit_helper`, `Probe_pressfit_holder`, `KlickyProbe_AB_mount_v2`, `KlickyProbe_AB_mount_v2_holder`, `Mount_magnet_holder`, `Mount_magnet_pressfit_helper`, `Mount_pressfit_holder_v2`, `Dock_mount_fixed_v2`, `usb_adapter_mount` | B02, B06, B07 |

**Re-arranged a plate in PrusaSlicer?** Save the project over `slicer/plates/<id>.3mf` and run
`python3 slicer/build_plates.py --from-3mf` — it re-slices the committed projects as they are (no re-packing),
refreshes `slicer/estimates.csv` and redraws every diagram from the 3MF, then `python3 slicer/check_docs.py`
tells you which numbers in the chapters need updating.

## Spool ledger

The margin above is a prediction. This table is where it gets checked. The *slicer g* column is the
prediction and it stands on its own; *actual g* is optional and wants a kitchen scale, if you own one —
weigh the spool before and after a plate and write the difference in. A plate that misses its slicer figure
by more than about 5 g means the flow is off, not that the estimate is wrong — check extrusion multiplier
before the next plate rather than after five more. Write each new spool's scale reading on its flange;
remaining = reading − (new reading − 800).

The accent spool is **Prusament ASA Blue** (Amazon, arrived 2026-09-12; exact colour name *(verify on the
spool)*), **superseded 2026-09-14**: the 800 g Prusament ASA Prusa Orange bought 2026-09-04 is now the spare,
and no plate in this build is printed in it.

Spool numbering: **#1 · #2 · #3** are the three 800 g Galaxy Black spools, **A1** the single 800 g accent
spool. *Remaining* is what should be left on the active spool once that plate is off the bed, if every
plate lands on its slicer number. Rows are in **print order** — numeric, B00 → B10, all before kit day.

**When to swap.** Never mid-plate on purpose — but a runout *during* a plate is fine on a part with no
bearing seat: the Core One+ runout sensor pauses, you load the next spool and it resumes. One runout is
predicted, on such a plate:

- **B09-P1** (Nevermore plenum, plenum lid, cartridge lid) — spool #2 has about 27 g left when it starts.

Four rules that override the ledger:

- **B01-P1 needs ≥ 201 g on the spool at start** (the ledger has it on a fresh spool #1 with 748 g — fine).
  If a reprint or an extra plate has pushed the active spool under ~230 g, start B01-P1 on a fresh one and
  re-derive the ledger from your weighings — a resume seam on a Z-drive body is not worth it.
- **B06-P1 starts spool #2** even though #1 still has ~133 g: the plate carries the Revo hotend seat and the
  Clockwork 2 gear bores, and a resume seam there is not worth 133 g. Keep the stub for a clip reprint.
- **B02-P1/P2/P3** run back to back on the one accent spool — two colour changes in the entire build, and
  that is the point ([print plan §4.3](../../voron-print-plan.md#43-spool-changes)).
- **B08-P4 starts with only ~27 g of cushion** on spool #2 (97 g for a 70 g plate). A runout there lands on a
  side skirt, where the seam shows. If #2 looks light or its flange reading says under ~90 g, start B08-P4 on
  #3; B09-P1 then runs whole on #3 and #2's stub is kept for clips.

| plate | slicer g | actual g (weigh) | spool # | remaining |
|---|---:|---:|---|---:|
| B00-P1 | 52 | | #1 | 748 |
| B01-P1 | 201 | | #1 | 547 |
| B01-P2 | 100 | | #1 | 447 |
| B02-P1 | 90 | | A1 | 710 |
| B02-P2 | 93 | | A1 | 617 |
| B02-P3 | 96 | | A1 | 521 |
| B03-P1 | 119 | | #1 | 328 |
| B04-P1 | 117 | | #1 | 211 |
| B05-P1 | 78 | | #1 | 133 |
| B06-P1 | 148 | | **#2 (fresh; #1's 133 g kept)** | 652 |
| B07-P1 | 102 | | #2 | 550 |
| B07-P2 | 124 | | #2 | 426 |
| B08-P1 | 99 | | #2 | 327 |
| B08-P2 | 108 | | #2 | 219 |
| B08-P3 | 122 | | #2 | 97 |
| B08-P4 | 70 | | #2 | 27 |
| B09-P1 | 63 | | **#2 → #3 mid-plate** | 764 |
| B09-P2 | 67 | | #3 | 697 |
| B09-P3 | 55 | | #3 | 642 |
| B09-P4 | 56 | | #3 | 586 |
| B09-P5 | 56 | | #3 | 530 |
| B10-P1 | 76 | | #3 | 454 |
| **TOTAL black** | **1813** | | 3 × 800 g | **587 g margin** (454 on #3 + 133 on #1) |
| **TOTAL blue** | **279** | | 1 × 800 g | **521 g margin** |

## When the printer stops

A plate that stops is almost always one of these five. Read the screen first, and keep hands out of the
chamber until the bed and nozzle have cooled: the nozzle runs at 265 °C and the bed at 110 °C. The helper
never reaches in.

| What you see | What to do |
|---|---|
| **"Filament runout during print, please insert new one"** | Normal: the sensor paused the plate. Follow the screen: it heats and walks you through the change. Load the next spool, check it extrudes clean, press **Continue**. A seam at that layer is fine on a part with no bearing seat; on a bearing-seat part, reprint it. Write the swap in the [ledger](#spool-ledger). |
| **The power went off** | Power Panic saved the plate. When power returns the printer offers to resume. First check every part is still stuck down: a long cut cools the bed and ASA lets go ("The heatbed cooled down during the power outage"). Stuck: resume and stay for 10 minutes. Loose: cancel and reprint the plate. Power Panic does not cover switching the printer off yourself. |
| **"The bed doesn't seem to be aligned properly. Run Z alignment procedure?"** before the plate starts | Cancel the print. Run **Control → Calibrations & Tests → Z alignment calibration**, press **Quit** when it asks, and start the plate again. Prompt again: brass-brush the hot nozzle clean, check nothing is under the sheet, and pass the [hot first-layer check](B00-calibration-and-jigs.md#before-b00-belt-and-hot-bed-checks) before the next plate. |
| **The nozzle taps the same spot over and over** while it probes | Usually ooze or dirt on the tip. Cancel, brass-brush the hot nozzle, wipe the sheet, start again. Still looping on a clean nozzle: stop the run until the cause is found; it is the printer, not the plate. |
| **Spaghetti, a part knocked loose, or a blob on the nozzle** | Stop the print from the knob menu. Let everything cool before you touch it, then clear the sheet. Plastic wrapped round the heater block: stop the run and ask Prusa support before the next plate; never pull on the wires. Reprint the whole plate: a part that stopped halfway is scrap, marked `R` per [Bins](#bins). |

A first layer that looks wrong is not in this table: stop it and fix the cause, as at
[Step B00.4](B00-calibration-and-jigs.md#step-b004-print), and see [troubleshooting](../15-troubleshooting.md) for
parts that print but measure wrong. Still stuck on the Core One+ itself: Prusa's 24/7 support chat, from
[help.prusa3d.com](https://help.prusa3d.com).

Sources: [Prusa KB — Filament runout #31829](https://help.prusa3d.com/article/filament-runout-31829-core-one-35829-core-one-l-17829-xl-26829-mk4s-13829-mk4-27829-mk3-9s-21829-mk3-9-28829-mk3-5s-23829-mk3-5-1282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) ·
[Power Panic](https://help.prusa3d.com/article/power-panic_2092) ·
[Heatbed cooled during the outage #31808](https://help.prusa3d.com/article/the-heatbed-cooled-down-during-the-power-outage-31808-core-one-35808-core-one-l-26808-mk4s-27808-mk3-9s-28808-mk3-5s-13808-mk4-21808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) ·
[Uneven bed #31111](https://help.prusa3d.com/article/uneven-bed-31111-core-one-35111-core-one-l-36111-core-one-indx_856294)

## B11 — bay ducting (PETG V0)

[B11](B11-bay-ducting.md) replaces LDO's five PVC wire ducts with two printed conduits, layout v3. It is
**outside the ASA run**: Prusament PETG V0 Jet Black on the textured sheet, sliced with
`slicer/bay-ducts-petg.ini`, not to Voron spec. Every hour and gram is a PrusaSlicer 2.9.6 estimate from
the committed projects, whose arrangements are still provisional until GUI QC. `check_docs.py` checks
this table, the run schedule and the ledger below against `slicer/estimates.csv`.

| group | plates | hours | g PETG V0 | feeds (assembly chapter) | print gate |
|---|---:|---:|---:|---|---|
| [B11](B11-bay-ducting.md) before kit | 3 | 11.9 | 173 | Ch 09 ducts; Ch 10 strip fin | none; the coupon, B11-P1, prints first |
| [B11](B11-bay-ducting.md) after the kit-day measurements | 2 | 13.1 | 175 | Ch 09 ducts | kit-day bay measurements; B11-P5 only if the gap is ≥ 25 mm and the coupon passed |
| **B11 total** | **5** | **25.0** | **348** | | |

**Filament:** 348 g needed from one 1 kg spool, **V1**, not yet bought → **652 g margin** if B11-P5 prints.

## B11 run schedule

Print whenever the Core One+ is free: all five are day plates. P1 to P3 need nothing measured; P4 and P5 wait
for the kit-day measurements. The # column carries on from the run schedule above.

| # | plate | hours | colour | slot | spool |
|---:|---|---:|---|---|---|
| 23 | B11-P1 | 0.4 | petg | day (the coupon, first) | V1 |
| 24 | B11-P2 | 6.9 | petg | day | V1 |
| 25 | B11-P3 | 4.6 | petg | day | V1 |
| 26 | B11-P4 | 6.3 | petg | day (after kit-day measurements) | V1 |
| 27 | B11-P5 | 6.8 | petg | day (only if gap ≥ 25 mm) | V1 |

## B11 spool ledger

Spool **V1** is one 1 kg Prusament PETG V0 Jet Black spool, not yet bought; weigh it the same way as the ASA
spools. Nothing else in the build prints from it.

| plate | slicer g | actual g (weigh) | spool # | remaining |
|---|---:|---:|---|---:|
| B11-P1 | 4 | | V1 | 996 |
| B11-P2 | 96 | | V1 | 900 |
| B11-P3 | 73 | | V1 | 827 |
| B11-P4 | 82 | | V1 | 745 |
| B11-P5 | 93 | | V1 | 652 |
| **TOTAL PETG V0** | **348** | | 1 × 1000 g | **652 g margin** |

## Add-on prints (outside the plates)

Optional parts that are on no plate and in no run total. Print each as its own job when the Core One+ is free.

| add-on | parts | hours | g ASA | sheet | feeds | files |
|---|---:|---:|---:|---|---|---|
| Nozzle scrubber with sheet stops (jinetix, remixed per machine) | 3 | 2.5 | 38 | smooth | Ch 13 Part L | `slicer/addons/scrubber-796563/` |
| Chamber exhaust housing (stock Voron 2.4r2): housing black; fan grill, access cover and 2 mounts blue | 5 | 7.1 | 101 | smooth | Ch 14 Part H | `slicer/addons/exhaust-voron2/` |

**The scrubber is not printed ahead.** Its parts are generated from this machine's measurements at
[Ch 13 Step 13.47](../13-initial-startup.md#step-1347-decide-what-to-print-or-stop) and printed at Step 13.48,
after kit day; that step can also say no-go. Galaxy Black ASA, `slicer/voron-coreone-asa.ini`, no supports;
it comes out of the black spare, not the ledger above. Hours and grams are the default set's PrusaSlicer 2.9.6
CLI estimate, not GUI-arranged. Also needs one Bambu A1 nozzle wiper (Ch 00 Step 00.8), in hand before
Step 13.45 measures it.

**The exhaust housing** is the stock Voron part set, unchanged, fetched from the pinned Voron-2 commit by
`python3 slicer/fetch_stls.py`. It is printed only after
[Ch 14 Step 14.25](../14-calibration.md#step-1425-inspect-the-back-of-the-machine-before-anything-is-bought)
has checked the back of the machine, as two jobs: the housing in Galaxy Black with `slicer/voron-coreone-asa.ini`
(66 g, 5 h 03 m), then the fan grill, access cover and two mounts in the blue accent with
`slicer/voron-accent-blue.ini` (35 g, 2 h 04 m). As oriented, no supports, smooth sheet; PrusaSlicer 2.9.6 CLI
estimates, not GUI-arranged. The grams come out of the spares, not the ledger above.

## Bench prints (outside the plates)

Workshop aids for the bench, not machine parts: on no plate, in no batch, in no run total and not in the
spool ledgers above. PLA, so the ASA spools are untouched. Print them any time the Core One+ is free before kit day.

| bench print | parts | hours | g PLA | sheet | feeds | files |
|---|---:|---:|---:|---|---|---|
| Hardware trays A–C, ultra-light Gridfinity bins on a 5 × 5 grid: A 6U, B 5U, C 4U | 3 | 18.6 | 652 | satin | Ch 00 Step 00.12 | `slicer/bench/hardware-trays/` |

**The hardware trays** take the kit's fastener bags on kit day
([Ch 00 Step 00.12](../00-before-you-start.md#step-0012-empty-the-fastener-bags-into-the-hardware-trays)):
tray A the M2 and M3 screws, tray B the M4 and M5 screws and the hammer-head T-nuts, tray C the nuts, inserts,
washers, spacers, magnets and roll-in T-nuts. Each is a standard Gridfinity bin on the same 5 × 5 footprint,
only as tall as its contents need, built ultra-light (hollow feet, two-perimeter walls), so it sits on any
Gridfinity baseplate and any tray stacks on any other. No lids. Three jobs, one tray per bed, each project as
committed: `0.20mm BALANCED @COREONE HF0.4` with Prusament PLA, 2 perimeters, 3 top and bottom layers, 10 %
infill, no supports, door open: A 7 h 28 m, B 5 h 50 m, C 5 h 17 m (PrusaSlicer 2.9.6 CLI estimates); none is lower than 4U, so nothing spills
when a tray tilts. For
two-colour labels, add a colour change in the layer slider at **40.4 mm** on A, **33.4 mm** on B and
**26.4 mm** on C. The generator, the fill check per compartment and the settings are in that folder's README.

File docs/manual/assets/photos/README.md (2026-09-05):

# Bench photos

Alex's own photos of this build (not mirrored/licensed third-party material —
see `docs/manual/assets/remote/` and its `SOURCES.txt` files for that). Filed
by `scripts/ingest_photos.py`; see `docs/manual/CONVENTIONS.md` → "Bench
photos" for the workflow and naming convention. Don't hand-edit filenames —
the chapter markdown links them by exact path.

Layout: `<chapter-slug>/<step>-<n>.jpg` (e.g. `10-wiring/10.58-2.jpg`), plus
an optional `<chapter-slug>/captions.yml` mapping filename to a one-line
caption.

`WANTED.md` in this folder (when present) is generated by
`scripts/photo_wanted.py` — don't hand-edit it.

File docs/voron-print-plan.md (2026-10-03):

# Voron 2.4 R2 (LDO Rev D+, 350) — Printed Parts Plan

Print every part on the **Prusa Core One+**, Prusament ASA, plate by plate, in build order.
Written to be followed with a 13-year-old: one plate = one job.

**Totals at a glance:** 22 plates · **157.0 h** print time · **1813 g Galaxy Black + 279 g ASA Blue** ·
against 2400 g black + 800 g blue on hand. PrusaSlicer 2.9.6 estimates, sliced from the committed
projects in `slicer/plates/` (§4.1); they replace a throughput model that read 134.3 h / 2248 g.
**Plus B11**, the bay ducting, outside those totals: 5 plates · 25.0 h · 348 g Jet Black PETG V0 (§3, §9).

```mascot
pose: base-3q
caption: One plate is one job. That is the entire plan. Making it look this simple took a champion.
```

---

## 0. What kit you actually have (established facts, with sources)

Everything below is from LDO's or Fabreeko's own pages, not from blogs.

| Fact | Value | Source |
|---|---|---|
| Kit | LDO Voron 2.4 R2 **Rev D+**, 350 mm | [Fabreeko product page](https://www.fabreeko.com/products/ldo-voron-v2-4-kit) |
| What "Rev D+" changes vs Rev D | "Nitehawk SB update with USB passthrough for USB based eddy current probes" (Mar 2026). **Mostly electrical — one printed-part change:** the V2 board's USB-adapter cover is `MotorDynamicsLab/Nitehawk-SB-V2/STLs/usb_adapter_mount_partial_cover.stl` (ground-lug mount), not the V1 `usb_adapter_mount.stl` cover — see batch B07. | [Fabreeko](https://www.fabreeko.com/products/ldo-voron-v2-4-kit) |
| Mainboard | **LDO Leviathan** (5× TMC2209 + 2× TMC5160HV for A/B, 48 V capable, integrated Raspberry Pi mount) | [Fabreeko](https://www.fabreeko.com/products/ldo-voron-v2-4-kit); [LDO wiring guide Rev D](https://docs.ldomotors.com/en/voron/voron2/wiring_guide_rev_d) |
| Toolhead board | **Nitehawk-SB V2** (STM32G0B1; USB toolhead PCB, **integrated ADXL**) — the "+" in Rev D+ | [LDO Voron 2.4 kit page](https://docs.ldomotors.com/en/voron/voron2) |
| Bed probe | **Omron inductive probe included AND a Klicky Probe Kit included** — you pick one. LDO: *"Instead of the included Omron inductive probe, we also provide the parts to build your machine using the optional Klicky mod by jlas1."* Wiring guide: *"Connect the inductive probe or Klicky cable to the PROBE port."* | [LDO kit page](https://docs.ldomotors.com/en/voron/voron2); [Rev D wiring guide](https://docs.ldomotors.com/en/voron/voron2/wiring_guide_rev_d); [Rev D 350 BOM](https://docs.ldomotors.com/en/voron/voron2/350_BOM/Rev_D) lists "Klicky Probe Kit ×1" |
| Z endstop | LDO **nozzle-probe PCB**; the printed part `nozzle_probe_ldo.stl` **is supplied printed in the kit** | [Rev D printed parts guide](https://docs.ldomotors.com/en/voron/voron2/printed_part_guide_rev_d) |
| XY endstop | **D2F microswitch PCB** — print `[a]_endstop_pod_D2F_switch`, *not* the hall-effect pod. No hall effect anywhere in this kit. | [Rev D printed parts guide](https://docs.ldomotors.com/en/voron/voron2/printed_part_guide_rev_d); [Build Notes p.145](https://docs.ldomotors.com/voron/voron2/build-faq) |
| Screen | **BigTreeTech Pi TFT4.3** (4.3" capacitive DSI). Print the LDO **BTT Pi TFT4.3 Mount**; **do not print the mini12864 parts.** | [Rev D printed parts guide](https://docs.ldomotors.com/en/voron/voron2/printed_part_guide_rev_d); [Rev D 350 BOM](https://docs.ldomotors.com/en/voron/voron2/350_BOM/Rev_D) |
| Filtration | **Nevermore Micro V5 Duo** (6×3 mm magnets), *instead of* the stock Voron exhaust filter. Stock exhaust housing is NOT built; the back panel is sealed with LDO's `exhaust_cover` + the stock `exhaust_filter_grill`. Carbon not included. | [LDO kit page](https://docs.ldomotors.com/en/voron/voron2); [Rev D printed parts guide](https://docs.ldomotors.com/en/voron/voron2/printed_part_guide_rev_d); [LDO Nevermore guide](https://ldomotion.com/guides/nevermore-v5-duo---v24) |
| Hotend | E3D **Revo High-Flow (Revo Voron form factor)** → Stealthburner printhead files `revo_voron/*` | [Fabreeko](https://www.fabreeko.com/products/ldo-voron-v2-4-kit); [SB printhead compatibility table](https://github.com/VoronDesign/Voron-Stealthburner/blob/main/STLs/Stealthburner/Printheads/README.md) ("E3D Revo Voron → E-RV") |
| Cable chains | **2-hole** ends → always take the `_2hole` variants, never `_3hole` | [Rev D printed parts guide](https://docs.ldomotors.com/en/voron/voron2/printed_part_guide_rev_d) |
| Power inlet | 1.0 mm AC inlet with integrated switch → `power_inlet_IECGS_1mm.stl` | [Rev D printed parts guide](https://docs.ldomotors.com/en/voron/voron2/printed_part_guide_rev_d) |
| Panels | Deck 3 mm acrylic, back 3 mm acrylic, bottom 4 mm acrylic, doors/sides/top 3 mm PC. Foam tape 1 mm and 3 mm both supplied. | [Rev D 350 BOM](https://docs.ldomotors.com/en/voron/voron2/350_BOM/Rev_D) |
| Rails | 1× stainless MGN12H 400 (X) + 6× stainless MGN9H 400 (2× Y, 4× Z) → print **both** rail guides | [Rev D 350 BOM](https://docs.ldomotors.com/en/voron/voron2/350_BOM/Rev_D) |
| Printed parts included | **NOT** included with the kit — except the ten LDO parts listed in §7 | [Fabreeko](https://www.fabreeko.com/products/ldo-voron-v2-4-kit) |
| Clicky-Clack door kit | Hardware + extrusions only. **STLs come from GitHub**, panel bought separately (you did). | [Fabreeko Clicky-Clack page](https://www.fabreeko.com/products/clickyclackydoor-kit-by-ldo) |
| Titanium backers | Gantry X/Y extrusion stiffeners; **no stock STL changes**. Fabreeko's set ships pre-tapped for the cable chain. See §6 note. | [Fabreeko backers](https://www.fabreeko.com/products/v2-4-trident-titanium-extrusion-backers); [whoppingpochard backer README](https://github.com/tanaes/whopping_Voron_mods/tree/main/extrusion_backers) |

**Parts where the kit revision changes the STL** — all three already resolved above, but flag them if the kit
that arrives is not Rev D/D+:

1. **Mainboard bracket.** Rev C and earlier shipped a BTT Octopus → `Octopus_bracket_set.stl`.
   Rev D ships Leviathan → `Leviathan_bracket_set.stl` (supplied printed). If a Rev C kit arrives, print the Octopus set.
2. **Raspberry Pi mount.** Rev C needed `beefy_raspberry_bracket.stl`; LDO Build Notes p.150 explicitly say
   *"it does not apply for rev D kits"* — Leviathan carries the Pi. Print nothing.
3. **XY endstop pod.** Rev A/B kits used a hall-effect endstop → `[a]_endstop_pod_hall_effect.stl` +
   `z_joint_upper_hall_effect.stl`. Rev C/D use the D2F PCB → `[a]_endstop_pod_D2F_switch.stl` + 4× plain `z_joint_upper_x4`.
4. **Display.** Rev A used the mini12864 skirt module; Rev C/D use the BTT touchscreen mount. Different front-skirt module entirely.
5. **Plug panel.** `power_inlet_IECGS_1mm` (Rev C/D, 1.0 mm inlet) vs `_1.2mm` vs `power_inlet_filtered`. LDO's own
   `plug_panel_1.2mm.stl` is marked deprecated for 2.4R2.

**Resolved 2026-09-05:** Rev D+ = Rev D + **Nitehawk-SB V2** — electrical plus one printed part
(`usb_adapter_mount_partial_cover`, batch B07). The Rev D printed-parts guide applies for everything else.
LDO still publishes no "Rev D+" printed-parts page (`printed_part_guide_rev_d_plus` returns 404); the only
open question for the Fabreeko Discord is whether one will ever be published.

---

## 1. Before the first plate

### 1.1 STL source of truth

Download these exact trees. Do not use a re-hosted zip or a Printables mirror.

| # | What | Repo / branch | Path |
|---|---|---|---|
| 1 | Voron 2.4 R2 core | `VoronDesign/Voron-2` branch **`Voron2.4`** | [`/STLs`](https://github.com/VoronDesign/Voron-2/tree/Voron2.4/STLs) |
| 2 | Stealthburner + Clockwork 2 | `VoronDesign/Voron-Stealthburner` branch **`main`** | [`/STLs`](https://github.com/VoronDesign/Voron-Stealthburner/tree/main/STLs) |
| 3 | LDO kit-specific | `MotorDynamicsLab/LDOVoron2` branch **`main`** | [`/STLs`](https://github.com/MotorDynamicsLab/LDOVoron2/tree/main/STLs) |
| 4 | LDO touchscreen mount | `MotorDynamicsLab/LDOVoronTrident` branch **`master`** | [`/STLs/BTT Pi TFT4.3 Mount`](https://github.com/MotorDynamicsLab/LDOVoronTrident/tree/master/STLs/BTT%20Pi%20TFT4.3%20Mount) |
| 5 | Nitehawk-SB | `MotorDynamicsLab/Nitehawk-SB` branch **`master`** | [`/STLs`](https://github.com/MotorDynamicsLab/Nitehawk-SB/tree/master/STLs) |
| 5b | Nitehawk-SB V2 (Rev D+ USB cover) | `MotorDynamicsLab/Nitehawk-SB-V2` branch **`master`** | [`/STLs`](https://github.com/MotorDynamicsLab/Nitehawk-SB-V2/tree/master/STLs) |
| 6 | Klicky probe | `jlas1/Klicky-Probe` branch **`main`** | [`/Probes/KlickyProbe/STL`](https://github.com/jlas1/Klicky-Probe/tree/main/Probes/KlickyProbe/STL) + [`/Printers/Voron/v1.8_v2.4_Legacy_Trident/v1.8_v2.4_Legacy_Trident_STL`](https://github.com/jlas1/Klicky-Probe/tree/main/Printers/Voron/v1.8_v2.4_Legacy_Trident/v1.8_v2.4_Legacy_Trident_STL) |
| 7 | Nevermore Micro V5 Duo | `nevermore3d/Nevermore_Micro` branch **`master`** | [`/V5_Duo/V2`](https://github.com/nevermore3d/Nevermore_Micro/tree/master/V5_Duo/V2) |
| 8 | Clicky-Clack door | `tanaes/whopping_Voron_mods` branch **`main`** | [`/clickyclacky_door/STLs`](https://github.com/tanaes/whopping_Voron_mods/tree/main/clickyclacky_door/STLs) |
| 9 | Backer-aware cable bridge (conditional) | `tanaes/whopping_Voron_mods` branch **`main`** | [`/extrusion_backers/STLs`](https://github.com/tanaes/whopping_Voron_mods/tree/main/extrusion_backers/STLs) |

The Voron repos have no release tags; take the branch head and **record the commit SHA in a text file next to
your STLs** so a mid-build reprint is identical to the first print.

### 1.2 Colour key (Voron's own naming convention)

From the [2.4r2 Assembly Manual p.4–5](https://github.com/VoronDesign/Voron-2/blob/Voron2.4/Manual/Assembly_Manual_2.4r2.pdf)
and the [Stealthburner STL README](https://github.com/VoronDesign/Voron-Stealthburner/blob/main/STLs/README.md):

| Prefix | Meaning | Our filament |
|---|---|---|
| *(none)* | Primary colour | **Prusament ASA Galaxy Black** |
| `[a]_` | Accent colour | **Prusament ASA Blue** |
| `[o]_` | Opaque — must block light | Galaxy Black (perfect) |
| `[c]_` | Clear / translucent | **Do not print** — LDO supplies the SB LED diffuser in clear PETG |
| `_x#` suffix | **Quantity required to build the machine** | e.g. `z_joint_lower_x4.stl` → print 4 copies of the file |

The `_x#` number is a *quantity*, not a hint that the file contains that many bodies. I checked every file:
only these contain more than one body — `[a]_stealthburner_main_body` (7 — built-in supports),
`cw2_captive_pcb_cover` (2), `usb_adapter_mount` (2 — mount base + cover), `Leviathan_bracket_set` (2 — L+R),
`bottom_panel_hinge_x2` (2), `cob_light_strip_mount_*` (2 — the mount is a 2-piece assembly),
`V2_Duo_Plenum` (2 — built-in support).
Clicky-Clack's `Hinge-L-sleeve-2X` / `-solid-2X` contain **one** body each — "2X" means print two.

### 1.3 Slicer: PrusaSlicer profile and the Voron overrides

**Slicer:** PrusaSlicer **2.9.6** (current stable, released 2026-06-25 —
[GitHub releases](https://github.com/prusa3d/PrusaSlicer/releases)). 3.0.0-alpha12 shipped 2026-09-21 as an
early preview. **Version posture (ruling 2026-09-26):** every batch, B00 through B11, is sliced on
2.9.6; the 3.0 preview is not used for this build. Any toolchain change re-runs
Gate A and Gate B (§1.4). The 3.0 deltas are kept as reference in
[`docs/manual/print/00-slicer-setup.md`](manual/print/00-slicer-setup.md#prusaslicer-30-preview).

**Base profiles — the ones every committed 3MF and both `.ini` bundles carry** (verified against
[`PrusaResearch.ini` @ version_2.9.6](https://github.com/prusa3d/PrusaSlicer/blob/version_2.9.6/resources/profiles/PrusaResearch.ini)).
The machine has the high-flow 0.4 nozzle, so the HF0.4 variants are the base;
[00-slicer-setup](manual/print/00-slicer-setup.md) owns the full reasoning:

- Printer: **`Prusa CORE One HF0.4 nozzle`** (printer model `Prusa CORE One & CORE One+`) — bed `250×220`, max height `270`, retract 0.7 mm @ 45 mm/s, z-hop 0.2 mm, wipe off. The projects carry the cold-probe start G-code, so the Plater shows it as `(modified)`.
- Filament: **`Prusament ASA @COREONE HF0.4`** — nozzle 265 °C, bed 110 °C, **chamber 55 °C** (minimum 40 °C), fan 20–25 %, first 4 layers fan off, density 1.07 g/cm³, max volumetric 26 mm³/s. The projects save it as `Prusament ASA @COREONE HF0.4 - Voron black` (accent: `- Voron blue`).
- Print: **`0.20mm STRUCTURAL @COREONE 0.4`** — *not* SPEED. There is no HF0.4 STRUCTURAL at 0.20 mm; this non-HF print preset is offered on the HF printer and is the one the projects use. STRUCTURAL is already the quality-biased profile
  (perimeters 70 mm/s vs SPEED's 170; external 50 vs 170; infill 120 vs 200).

**Overrides.** Column "source" = where the number comes from; **judgment** = my call, not a cited spec.

#### Print settings

| Setting | Prusa STRUCTURAL default | Set to | Why | Source |
|---|---|---|---|---|
| Layer height / first layer | 0.20 / 0.20 | **keep** | Voron spec | [Manual p.4](https://github.com/VoronDesign/Voron-2/blob/Voron2.4/Manual/Assembly_Manual_2.4r2.pdf) |
| Perimeters | 2 | **4** | Voron spec; wall count is what carries load in these parts | Manual p.4 |
| Top solid layers | 5 | **keep 5** | Voron spec | Manual p.4 |
| Bottom solid layers | 4 | **5** | Voron spec says 5 top **and** bottom | Manual p.4 |
| Fill density | 15 % | **40 %** | Voron spec | Manual p.4 |
| Fill pattern | Grid | **keep Grid** | Voron allows grid/gyroid/honeycomb/triangle/cubic | Manual p.4 |
| Extrusion width (default, perimeter, external, infill, solid) | 0.45 | **0.40** | Voron: *"Extrusion width — Recommended: Forced 0.4 mm"*. Ribs, bosses and bearing seats were drawn around a 0.4 bead. | Manual p.4 |
| First layer extrusion width | 0.50 | **keep 0.50** | wider first bead = better ASA adhesion | judgment |
| Top infill extrusion width | 0.42 | **0.40** | consistency | judgment |
| Perimeter generator | Arachne | **keep Arachne** | Voron's "forced 0.4" predates Arachne. Arachne varies bead width *on purpose* and handles Voron's thin ribs better than Classic. Setting nominal width to 0.4 gives Arachne the right target. | judgment |
| Supports | on (auto **off**) | **None** | Every Voron/LDO/Nevermore STL is pre-oriented with built-in break-away supports where needed | Manual; [Nevermore README](https://github.com/nevermore3d/Nevermore_Micro#assembly); [Klicky STL README](https://github.com/jlas1/Klicky-Probe/blob/main/Probes/KlickyProbe/STL/README.md) |
| Seam position | Aligned | **Rear** | keeps the seam off the visible outward faces of skirts and the toolhead | your build spec |
| Skirt loops | 0 | **1 loop, 3 mm gap, min length 4 mm** | primes after the long ASA purge; lets you abort in the first 60 s if the first layer is wrong | judgment |
| Brim | off | **off by default; 5 mm on the tall/narrow parts, 3 mm on the 150–182 mm skirts** — list in §5 | ASA corner lift on long flat parts and tippy tall parts | [Prusa warping KB](https://help.prusa3d.com/article/warping_2011); judgment |
| **XY size compensation** | 0 | **keep 0** | Voron: *"The parts have been designed with ABS/ASA shrinkage in mind… shrinkage should be set to 100 %. Compensating for this is likely to make bearing fits and screw holes too large."* | [docs.vorondesign.com/materials.html](https://docs.vorondesign.com/materials.html) |
| Elephant-foot compensation | 0.20 | **keep 0.20 for now, verify on the cube** | it shrinks only the *first* layer; several Voron parts have a bearing bore starting at the bed. Measure before changing. | judgment |
| External perimeter speed | 50 | **35** | surface finish and corner accuracy on the visible skirts; speed is not a goal here | judgment |
| Perimeter speed | 70 | **55** | more time at temperature per bead = better interlayer bond at 4 walls | judgment |
| Infill speed | 120 | **100** | interior quality and less pressure variation into the perimeters | judgment |
| Solid infill speed | 140 | **110** | flatter top/bottom faces on the skirts | judgment |
| Top solid infill | 80 | **keep 80** | already conservative | — |
| First layer speed | 45 | **25** | ASA on smooth PEI is the single biggest failure mode; slow the first layer | [Prusa ASA KB](https://help.prusa3d.com/article/asa_1809); judgment |
| External perimeters first | off | **keep off** | inside-out gives better dimensional accuracy on holes; only flip it if you see external-perimeter bulging | judgment |
| Dynamic overhang speeds | on (15/25/45/90 %) | **keep on** | Prusa tuned these for the Core One's part fan | — |
| Ironing | off | **keep off** | — | — |

#### Filament settings (Prusament ASA @COREONE HF0.4)

| Setting | Profile default | Set to | Why | Source |
|---|---|---|---|---|
| **Shrinkage compensation XY** | **0.22 %** | **0 %** | Same rule as XY size compensation — PrusaSlicer 2.9 scales ASA parts up 0.22 %; that is +0.15 mm on a 66.7 mm Z-drive body and +0.035 mm on every 16 mm bearing bore, compounding with any flow error. **This is the single most important override in this document.** | [docs.vorondesign.com/materials.html](https://docs.vorondesign.com/materials.html) + profile value |
| Shrinkage compensation Z | 0.22 % | **0 %** | same reason | as above |
| Nozzle / first-layer nozzle | 265 / 265 °C | **keep** | Prusa's own Prusament ASA values for the HF nozzle on this machine | profile |
| Bed / first-layer bed | 110 / 110 °C | **keep** | Prusa ASA guidance is ≥100 °C bed | profile; [Prusa ASA KB](https://help.prusa3d.com/article/asa_1809) |
| Chamber temperature | 55 °C | **keep 55** | matches the 55–60 °C a real Voron sees; the Voron parts are designed for it | profile; [docs.vorondesign.com/materials.html](https://docs.vorondesign.com/materials.html) |
| Chamber minimal temperature | 40 °C | **keep 40** | printer will not start until the chamber reaches 40 °C — this *is* your preheat gate | profile |
| Min / max fan | 20 / 25 % | **keep for B00–B01, then decide** | Prusa tuned this for the Core One chamber. If you see perimeter separation on the Z-drive bodies, drop to **0 / 15 %** and keep bridge fan at 25 %. | profile; [Ellis — Perimeter Separation](https://ellis3dp.com/Print-Tuning-Guide/articles/troubleshooting/perimeter_separation.html) |
| Max volumetric speed | 26 mm³/s | **keep** | not a limit at these speeds (peak ≈8.8 mm³/s) | profile |
| Retraction / z-hop | 0.7 mm / 0.2 mm | **keep** | Nextruder-specific; do not touch | printer profile |

#### Drying

ASA is mildly hygroscopic. A fresh, sealed Prusament spool used within ~2 weeks needs nothing.
Dry at **80 °C for 4 h** if a spool has been open longer, or the moment you see stringing, matte striping, or
popping; on the Sunlu SP2 (70 °C cap) that is **70 °C for 6 h** with the port plugs out. Keep the active spool in one USS Drybox during the run. Voron parts are structural — this is the
material where wet filament actually costs you strength.
(Sources: [Prusa ASA KB](https://help.prusa3d.com/article/asa_1809); the project's drying rules, `AGENTS.md` › Materials & filament.)

### 1.4 Calibration sequence — run this before B00, and again after any toolchain change

1. **Advanced Filtration Kit — already fitted** (2026-09-12), so there is nothing to install here. You're
   about to run ~157 h of ASA in an enclosure: on the first ASA plate confirm the blower runs and the bypass
   flaps seal. One spare cartridge is still to buy (~600 print-h each, 1–2 wk Prusa lead time).
2. **Firmware ≥ 6.8.1** on the Core One+ (6.9.x is INDX-only until the INDX kit is fitted).
3. **First layer: there is nothing to run.** The Core One+ has no first-layer calibration wizard — the
   Nextruder loadcell sets Z automatically before every print, as part of mesh bed levelling
   ([Prusa KB — Live Adjust Z](https://help.prusa3d.com/article/live-adjust-z_112427)). Judge B00-P1's
   first layer by [Ellis' smooth-bottom method](https://ellis3dp.com/Print-Tuning-Guide/articles/first_layer_squish.html):
   smooth, no visible gaps between beads, no ridging. If it needs a nudge, long-press the knob during the
   first layer → Live Adjust Z — and note the nudge is *not* saved for the next print, so fix the cause
   (sheet seating, glue film, nozzle seat) rather than nudging every plate.
4. **Print plate B00-P1** (§3). It carries the coupons for both gates.
5. **Measure with the calipers, at mid-height (not across the first layer).** The gate is in two parts,
   because three coupons need parts that only arrive with the Voron kit.

   **Gate A — no kit needed (the cube):**

   | Coupon | Nominal | Accept | If out of spec |
   |---|---|---|---|
   | `Voron_Design_Cube_v7` X and Y | 30.00 mm | **±0.15 mm** | >+0.15: confirm shrinkage compensation is 0 % and XY compensation is 0. Still over → reduce extrusion multiplier in 1 % steps ([Ellis — Extrusion Multiplier](https://ellis3dp.com/Print-Tuning-Guide/articles/extrusion_multiplier.html)). Do **not** dial in negative XY compensation; you will wreck the bearing fits. |
   | `Voron_Design_Cube_v7` Z | 30.00 mm | **±0.10 mm** | over → first layer under-squished; under → over-squished |
   | Cube first layer vs mid-height X | — | difference **≤ 0.15 mm** | bigger → elephant-foot compensation is wrong; adjust in 0.05 mm steps |
   | Cube corner snap test | — | must **not** delaminate along a layer line | delamination → chamber too cold or fan too high → drop min/max fan to 0/15 % |

   **Gate B — inserts and a caliper now, on what is already on the bench; bearing and rail on kit day:**

   | When | Coupon | Nominal | Accept | If out of spec |
   |---|---|---|---|---|
   | now | `Heatset_Practice` | 7 × M3×H5 inserts from the KADRICK kit, all seven pockets (all 153 kit inserts stay for the build) | insert sits flush to 0.2 mm proud, boss does not bulge > 0.2 mm | bulging → iron too hot or pushed too fast; this is a technique problem, not a slicer one. This coupon is the adult's practice part and has no other use: Ch 00 Steps 00.14–00.15 are this row. Set all seven before touching a real part. The iron stays with the adult; once the coupon has cooled, the helper reads the caliper on each insert and calls flush or proud. |
   | now | `z_drive_retainer_a` 625-2RS pocket (on the same plate) | **16.30 mm**, measured off the STL | caliper reads 16.30 mm ±0.15 | over → confirm shrinkage compensation is 0 % and XY compensation is 0, then raise extrusion multiplier 1 %. Under → reduce it 1 %. Reprint the retainer and the cube, re-pass Gate A. |
   | kit day | the same pocket, on a real 625-2RS (16 mm OD; F695 is the A/B-drive bearing, not the Z drive) | — | bearing presses in with thumb pressure, no rocking | **The press fit the caliper stood in for.** |
   | kit day | `MGN12_rail_guide` on the real MGN12 rail | — | slides on with light finger pressure | very tight → over-extrusion; loose → under-extrusion |

6. **Gate A passed → B02, B07 and the cosmetics B08 → B09 → B10** are released (the whole run prints on the
   current Gen 1 GT2 belts — §8). **Gate B passed → B01, then B03–B06.** Never start B01 or B03–B06 on Gate A alone — that is
   58.4 h and 763 g of bearing-seat and bore parts against an unverified fit. Nothing is bought to bring
   Gate B forward: its insert row runs on the KADRICK inserts already on the bench and its bore row is a
   caliper, so both run in the same week as Gate A. The **bearing press** and the **MGN12 rail row** wait
   for the kit, and the rail row gates nothing but a 20-minute reprint of the `MGN12_rail_guide` jig.

**Quality gate before every later batch:** look at the *last* plate you pulled off. If any part shows
(a) a lifted corner, (b) a delaminated layer, or (c) a bore/boss that failed a test fit — fix that before
starting the next plate, don't print 100 g on top of a known problem.

---

## 2. Which parts gate the frame and Z-drive steps

**Frame** (Assembly Manual ch. *Frame*, p.12–21): **no printed part is required.** The frame is extrusion,
corner brackets and hardware. You can square the frame the day the kit lands — and by then every plate in
the build is already printed and binned.

**Z rails** (p.24–27, inside ch. *Z Drives and Idlers*): the only printed items are the optional-but-worth-it
alignment jigs — `MGN12_rail_guide_x2` ×2 and `MGN9_rail_guide_x2` ×2. Both are on plate **B00-P1**.

**Z Drives and Idlers** (p.22–51) — the first step that genuinely stops without plastic. It needs:

- all of **Batch 1** (Z-drive bodies, retainers, motor mounts, Z-tensioner brackets, deck supports), **and**
- these accent parts from **Batch 2**: `[a]_z_drive_baseplate_a/b` ×2 each, `[a]_belt_tensioner_a/b` ×2 each,
  `[a]_z_tensioner_9mm_x4` ×4.

So the minimum to start building is **B00 + B01 + B02-P1 + B02-P3** ≈ 34 h of printing.
Everything else can be printed while you build.

**What prints before the kit: all of it.** Fabreeko's kit is not expected before late November 2026 (§8),
and with Gate B's caliper and insert rows run early on what is already on the bench (§1.4) nothing is left
to gate a batch.
The order is therefore the plain numeric one — pre-B00 checks on the current Gen 1 belts, then
**B00 → B01 → B02 → … → B10**, 157.0 h ≈ 16 printer-days ≈ 3–4 weeks at two plate swaps a day. On kit day the frame (no printed part) and
Ch 00 start at once with every bin full, and no assembly chapter ever waits on a plate. The only print job
the build may still owe is the `deck_support_4mm` reprint, if the deck panel calipers 4 mm (§6).

**Tall parts (> 150 mm in Z): none.** The tallest part in the whole set is the Clicky-Clack `Handle` at
**60.0 mm**. Orientation rules that do matter are in §5.

---

## 3. The batches

Format for each: what it unlocks (manual chapter name), plates, hours, grams, then the parts table
(exact filenames, repo path, qty, colour, grams and hours per copy).

**Batch headers and plate lines are PrusaSlicer 2.9.6 estimates** — sliced from the committed projects in
`slicer/plates/`, with this build's overrides, the real arrangement and the real brims (§4.1). The per-copy
`g ea` / `h ea` columns inside the parts tables are still the older geometry model, kept for relative sizing
only; they do not sum to the plate line, which also carries skirt, brim and travel.

---

### Batch B00 — Calibration & jigs · **1 plate · 4.0 h · 52 g black**
**Unlocks:** *Frame* (rail installation aids) — and gates every batch after it.

| STL | Repo path | Qty | Colour | g ea | h ea |
|---|---|---:|---|---:|---:|
| `Voron_Design_Cube_v7.stl` | Voron-2 `STLs/Test_Prints/` | 1 | Black | 16.2 | 0.98 |
| `Heatset_Practice.stl` | Voron-2 `STLs/Test_Prints/` | 1 | Black | 6.5 | 0.39 |
| `MGN12_rail_guide_x2.stl` | Voron-2 `STLs/Tools/` | 2 | Black | 3.2 | 0.20 |
| `MGN9_rail_guide_x2.stl` | Voron-2 `STLs/Tools/` | 2 | Black | 2.7 | 0.17 |
| `pulley_jig.stl` | Voron-2 `STLs/Tools/` | 1 | Black | 2.8 | 0.17 |
| `z_drive_retainer_a_x2.stl` | Voron-2 `STLs/Z_Drive/` | 1 *(of the 2 needed)* | Black | 19.5 | 1.15 |

**Plate B00-P1** — all of the above. 4.0 h, 52 g.
The `z_drive_retainer_a` here is deliberate: it is your bearing-press-fit coupon, and it is a real part you
will use, so nothing is wasted.

---

### Batch B01 — Z drive assemblies · **2 plates · 22.8 h · 301 g black**
**Unlocks:** *Z Drives and Idlers* (p.22–51) and the deck-panel step (p.28–30).

| STL | Repo path | Qty | Colour | g ea | h ea |
|---|---|---:|---|---:|---:|
| `z_drive_main_a_x2.stl` | Voron-2 `STLs/Z_Drive/` | 2 | Black | 39.4 | 2.31 |
| `z_drive_main_b_x2.stl` | Voron-2 `STLs/Z_Drive/` | 2 | Black | 39.4 | 2.31 |
| `z_drive_retainer_a_x2.stl` | Voron-2 `STLs/Z_Drive/` | 1 *(second copy; first was on B00)* | Black | 19.5 | 1.15 |
| `z_drive_retainer_b_x2.stl` | Voron-2 `STLs/Z_Drive/` | 2 | Black | 19.5 | 1.15 |
| `z_motor_mount_a_x2.stl` | Voron-2 `STLs/Z_Drive/` | 2 | Black | 11.9 | 0.75 |
| `z_motor_mount_b_x2.stl` | Voron-2 `STLs/Z_Drive/` | 2 | Black | 11.9 | 0.75 |
| `z_tensioner_bracket_a_x2.stl` | Voron-2 `STLs/Z_Idlers/` | 2 | Black | 13.0 | 0.79 |
| `z_tensioner_bracket_b_x2.stl` | Voron-2 `STLs/Z_Idlers/` | 2 | Black | 13.0 | 0.79 |
| `deck_support_3mm_x8.stl` | Voron-2 `STLs/Panel_Mounting/` | 8 | Black | 1.1 | 0.07 |

- **Plate B01-P1** (15.2 h, 201 g): `z_drive_main_a` ×2, `z_drive_main_b` ×2, `z_drive_retainer_a` ×1, `z_drive_retainer_b` ×2.
  Longest plate in the build — start it in the morning, not at bedtime.
- **Plate B01-P2** (7.6 h, 100 g): `z_motor_mount_a` ×2, `z_motor_mount_b` ×2, `z_tensioner_bracket_a` ×2, `z_tensioner_bracket_b` ×2, `deck_support_3mm` ×8.

**Deck supports (verify):** LDO's Rev D printed-parts guide says *"Our kit ships with 4 mm deck panels, use 4 mm
deck support clips"*, but the Rev D 350 BOM lists the deck panel as **3 mm** acrylic (the 4 mm panel is the
*bottom* panel). The size-specific 350 BOM wins: print `deck_support_3mm_x8` ×8, and if the deck panel
measures 4 mm when it arrives, reprint `deck_support_4mm_x8` — 8 g, 30 minutes.
([guide](https://docs.ldomotors.com/en/voron/voron2/printed_part_guide_rev_d), [BOM](https://docs.ldomotors.com/en/voron/voron2/350_BOM/Rev_D), [Build Notes p.29-30](https://docs.ldomotors.com/voron/voron2/build-faq))

---

### Batch B02 — **The accent day** (every accent part in the build) · **3 plates · 21.9 h · 279 g blue**
**Unlocks:** the accent half of *Z Drives and Idlers*, *A/B Drives and Idlers*, *Gantry*, *Stealthburner*,
*Skirts* and the Clicky-Clack door.

All 49 accent parts are printed in one continuous blue session so the accent spool is mounted exactly
once. **Two colour changes in the whole build: black → blue here, blue → black after.**
Everything is printed before the kit arrives anyway, so nothing waits on this.

| STL | Repo path | Qty | g ea | h ea |
|---|---|---:|---:|---:|
| `[a]_z_drive_baseplate_a_x2.stl` | Voron-2 `STLs/Z_Drive/` | 2 | 9.7 | 0.57 |
| `[a]_z_drive_baseplate_b_x2.stl` | Voron-2 `STLs/Z_Drive/` | 2 | 9.7 | 0.57 |
| `[a]_belt_tensioner_a_x2.stl` | Voron-2 `STLs/Z_Drive/` | 2 | 1.9 | 0.12 |
| `[a]_belt_tensioner_b_x2.stl` | Voron-2 `STLs/Z_Drive/` | 2 | 1.9 | 0.12 |
| `[a]_z_tensioner_9mm_x4.stl` | Voron-2 `STLs/Z_Idlers/` | 4 | 8.1 | 0.49 |
| `[a]_tensioner_left.stl` | Voron-2 `STLs/Gantry/Front_Idlers/` | 1 | 7.4 | 0.45 |
| `[a]_tensioner_right.stl` | Voron-2 `STLs/Gantry/Front_Idlers/` | 1 | 7.4 | 0.45 |
| `[a]_cable_cover.stl` | Voron-2 `STLs/Gantry/AB_Drive_Units/` | 1 | 8.0 | 0.51 |
| `[a]_z_chain_retainer_bracket_x2.stl` | Voron-2 `STLs/Gantry/AB_Drive_Units/` | 2 | 0.6 | 0.04 |
| `[a]_endstop_pod_D2F_switch.stl` | Voron-2 `STLs/Gantry/X_Axis/XY_Joints/` | 1 | 8.1 | 0.49 |
| `[a]_xy_joint_cable_bridge_2hole.stl` | Voron-2 `STLs/Gantry/X_Axis/XY_Joints/` | 1 | 9.2 | 0.56 |
| `XY_cable_chain_bridge-Igus-3mm_backer.stl` | whopping\_Voron\_mods `extrusion_backers/STLs/` | 1 *(alternate — see §6)* | 9.1 | 0.58 |
| `[a]_z_belt_clip_lower_x4.stl` | Voron-2 `STLs/Gantry/` | 4 | 2.3 | 0.14 |
| `[a]_z_belt_clip_upper_x4.stl` | Voron-2 `STLs/Gantry/` | 4 | 2.4 | 0.14 |
| `[a]_stealthburner_main_body.stl` | Stealthburner `STLs/Stealthburner/` | 1 | 46.5 | 2.73 |
| `[a]_guidler_a.stl` | Stealthburner `STLs/Clockwork2/Direct_Drive/` | 1 | 3.7 | 0.24 |
| `[a]_guidler_b.stl` | Stealthburner `STLs/Clockwork2/Direct_Drive/` | 1 | 2.1 | 0.14 |
| `[a]_latch.stl` | Stealthburner `STLs/Clockwork2/Direct_Drive/` | 1 | 3.5 | 0.22 |
| `[a]_latch_shuttle.stl` | Stealthburner `STLs/Clockwork2/Direct_Drive/` | 1 | 1.7 | 0.11 |
| `[a]_pcb_spacer.stl` | Stealthburner `STLs/Clockwork2/` | 1 *(spare — kit supplies one)* | 0.3 | 0.02 |
| `[a]_belt_guard_a_x2.stl` | Voron-2 `STLs/Skirts/` | 2 | 5.4 | 0.33 |
| `[a]_belt_guard_b_x2.stl` | Voron-2 `STLs/Skirts/` | 2 | 5.4 | 0.33 |
| `[a]_fan_grill_a_x2.stl` | Voron-2 `STLs/Skirts/` | 2 | 5.9 | 0.34 |
| `[a]_fan_grill_b_x2.stl` | Voron-2 `STLs/Skirts/` | 2 | 5.9 | 0.34 |
| `[a]_fan_grill_retainer_x2.stl` | Voron-2 `STLs/Skirts/` | 2 | 4.2 | 0.25 |
| `[a]_keystone_blank_insert.stl` | Voron-2 `STLs/Skirts/` | 2 *(1 used + 1 spare; LDO ships one CAT6 keystone)* | 2.5 | 0.16 |
| `[a]_faceplate.stl` | LDOVoronTrident `STLs/BTT Pi TFT4.3 Mount/` | 1 | 6.6 | 0.41 |
| `ldo_bestagon_insert.stl` | LDOVoron2 `STLs/` | 1 | 3.0 | 0.18 |
| `Handle.stl` | whopping\_Voron\_mods `clickyclacky_door/STLs/` | 1 | 33.7 | 2.03 |

- **Plate B02-P1** (7.0 h, 90 g): `[a]_stealthburner_main_body`, `[a]_faceplate`, `[a]_cable_cover`, `[a]_z_drive_baseplate_a` ×2, `[a]_z_drive_baseplate_b` ×2.
- **Plate B02-P2** (7.3 h, 93 g): `Handle`, `[a]_fan_grill_a` ×2, `[a]_fan_grill_b` ×2, `[a]_fan_grill_retainer` ×2, `[a]_belt_guard_a` ×2, `[a]_belt_guard_b` ×2, `[a]_tensioner_left`, `[a]_tensioner_right`.
- **Plate B02-P3** (7.6 h, 96 g): everything else — the 29 small accent parts.

Notes: the SB main body has **built-in supports** — snap them out, don't cut
([SB manual, "Remove built-in supports"](https://github.com/VoronDesign/Voron-Stealthburner/blob/main/Manual/Assembly_Manual_SB.pdf)).
`Handle.stl` is 60 mm tall on a 68×19 footprint — give it a 5 mm brim (§5).

---

### Batch B03 — A/B drive units + front idlers · **1 plate · 8.5 h · 119 g black**
**Unlocks:** *A/B Drives and Idlers* (p.62–81).

| STL | Repo path | Qty | Colour | g ea | h ea |
|---|---|---:|---|---:|---:|
| `a_drive_frame_lower.stl` | Voron-2 `STLs/Gantry/AB_Drive_Units/` | 1 | Black | 22.4 | 1.32 |
| `a_drive_frame_upper.stl` | Voron-2 `STLs/Gantry/AB_Drive_Units/` | 1 | Black | 21.8 | 1.28 |
| `b_drive_frame_lower.stl` | Voron-2 `STLs/Gantry/AB_Drive_Units/` | 1 | Black | 20.5 | 1.21 |
| `b_drive_frame_upper.stl` | Voron-2 `STLs/Gantry/AB_Drive_Units/` | 1 | Black | 21.3 | 1.25 |
| `front_idler_left_lower.stl` | Voron-2 `STLs/Gantry/Front_Idlers/` | 1 | Black | 7.7 | 0.46 |
| `front_idler_left_upper.stl` | Voron-2 `STLs/Gantry/Front_Idlers/` | 1 | Black | 14.1 | 0.84 |
| `front_idler_right_lower.stl` | Voron-2 `STLs/Gantry/Front_Idlers/` | 1 | Black | 13.8 | 0.83 |
| `front_idler_right_upper.stl` | Voron-2 `STLs/Gantry/Front_Idlers/` | 1 | Black | 7.9 | 0.47 |

- **Plate B03-P1** (8.5 h, 119 g): both sides — `a_drive_frame_lower`, `a_drive_frame_upper`,
  `front_idler_right_lower`, `front_idler_right_upper`, `b_drive_frame_lower`, `b_drive_frame_upper`,
  `front_idler_left_lower`, `front_idler_left_upper`.

A and B were on separate plates until 2026-09-06, when the two were merged to cut a plate swap. The trade is
real: a failed plate now costs both drive units instead of one, so watch the first layer before walking away.

---

### Batch B04 — XY joints + X carriage · **1 plate · 8.6 h · 117 g black**
**Unlocks:** *Gantry* (p.82–107).

| STL | Repo path | Qty | Colour | g ea | h ea |
|---|---|---:|---|---:|---:|
| `xy_joint_left_lower_MGN12.stl` | Voron-2 `STLs/Gantry/X_Axis/XY_Joints/` | 1 | Black | 32.0 | 1.90 |
| `xy_joint_left_upper_MGN12.stl` | Voron-2 `STLs/Gantry/X_Axis/XY_Joints/` | 1 | Black | 11.7 | 0.70 |
| `xy_joint_right_lower_MGN12.stl` | Voron-2 `STLs/Gantry/X_Axis/XY_Joints/` | 1 | Black | 32.7 | 1.94 |
| `xy_joint_right_upper_MGN12.stl` | Voron-2 `STLs/Gantry/X_Axis/XY_Joints/` | 1 | Black | 11.1 | 0.67 |
| `x_frame_V2TR_MGN12_left.stl` | Voron-2 `STLs/Gantry/X_Axis/X_Carriage/` | 1 | Black | 17.1 | 1.02 |
| `x_frame_V2TR_MGN12_right.stl` | Voron-2 `STLs/Gantry/X_Axis/X_Carriage/` | 1 | Black | 17.2 | 1.03 |
| `probe_retainer_bracket.stl` | Voron-2 `STLs/Gantry/X_Axis/X_Carriage/` | 1 | Black | 0.5 | 0.03 |

**Plate B04-P1** — all seven. 8.6 h, 117 g.

`probe_retainer_bracket` is only used if you run the Omron inductive probe. It costs 0.5 g — print it, decide later.
If the probe barrel measures 9 mm rather than 8 mm, print `probe_retainer_bracket_9mm.stl` instead **(verify on arrival)**.
`x_frame_V2TR_MGN12_*` are the R2 / Clockwork-2 carriage halves — LDO Build Notes p.129-130 warn specifically about
using the wrong X-carriage here.

---

### Batch B05 — Z joints + Z chain · **1 plate · 6.4 h · 78 g black**
**Unlocks:** *Z Axis* (p.108–123) and *A/B Belts* (p.124–145).

| STL | Repo path | Qty | Colour | g ea | h ea |
|---|---|---:|---|---:|---:|
| `z_joint_lower_x4.stl` | Voron-2 `STLs/Gantry/Z_Joints/` | 4 | Black | 9.1 | 0.56 |
| `z_joint_upper_x4.stl` | Voron-2 `STLs/Gantry/Z_Joints/` | 4 | Black | 6.6 | 0.41 |
| `z_chain_bottom_anchor.stl` | Voron-2 `STLs/Gantry/` | 1 | Black | 9.1 | 0.55 |
| `z_chain_guide.stl` | Voron-2 `STLs/Gantry/` | 1 | Black | 6.0 | 0.37 |
| `z_rail_stop_x4.stl` | LDOVoron2 `STLs/` | 4 | Black | 1.4 | 0.11 |

**Plate B05-P1** — all fourteen. 6.4 h, 78 g.

Print **4× `z_joint_upper_x4`** and **zero** `z_joint_upper_hall_effect.stl` — that variant exists only for
hall-effect XY endstops, which this kit does not use
([LDO Build Notes p.145](https://docs.ldomotors.com/voron/voron2/build-faq)).
The LDO `z_rail_stop` is optional but stops a Z carriage from falling off the top of a rail and spilling its balls.

---

### Batch B06 — Toolhead: Stealthburner, Clockwork 2, Klicky · **1 plate · 12.1 h · 148 g black**
**Unlocks:** *Stealthburner* (p.146–147, then the separate Stealthburner manual). Also requires
`probe_retainer_bracket.stl` from B04.

| STL | Repo path | Qty | Colour | g ea | h ea |
|---|---|---:|---|---:|---:|
| `stealthburner_printhead_revo_voron_front.stl` | Stealthburner `STLs/Stealthburner/Printheads/revo_voron/` | 1 | Black | 40.6 | 2.38 |
| `stealthburner_printhead_revo_voron_rear_cw2.stl` | Stealthburner `STLs/Stealthburner/Printheads/revo_voron/` | 1 | Black | 15.0 | 0.90 |
| `[o]_stealthburner_LED_carrier.stl` | Stealthburner `STLs/Stealthburner/` | 1 | Black (opaque) | 0.9 | 0.06 |
| `[o]_stealthburner_LED_diffuser_mask.stl` | Stealthburner `STLs/Stealthburner/` | 1 | Black (opaque) | 0.3 | 0.03 |
| `main_body.stl` (Clockwork 2) | Stealthburner `STLs/Clockwork2/Direct_Drive/` | 1 | Black | 23.7 | 1.40 |
| `motor_plate.stl` (Clockwork 2) | Stealthburner `STLs/Clockwork2/Direct_Drive/` | 1 | Black | 14.1 | 0.83 |
| `cw2_captive_pcb_cover.stl` | Nitehawk-SB `STLs/` | 1 | Black | 10.9 | 0.69 |
| `KlickyProbe_v2.stl` | Klicky `Probes/KlickyProbe/STL/` | 2 *(1 + spare, per the mod's own advice)* | Black | 2.5 | 0.16 |
| `Probe_Dock_v2.1.stl` | Klicky `Probes/KlickyProbe/STL/` | 1 | Black | 3.1 | 0.19 |
| `Probe_magnet_holder.stl` | Klicky `Probes/KlickyProbe/STL/` | 1 | Black | 2.3 | 0.14 |
| `Probe_magnet_pressfit_helper.stl` | Klicky `Probes/KlickyProbe/STL/` | 1 | Black | 1.6 | 0.10 |
| `Probe_pressfit_holder.stl` | Klicky `Probes/KlickyProbe/STL/` | 1 | Black | 4.6 | 0.29 |
| `KlickyProbe_AB_mount_v2.stl` | Klicky `Printers/Voron/v1.8_v2.4_Legacy_Trident/v1.8_v2.4_Legacy_Trident_STL/` | 1 | Black | 4.4 | 0.29 |
| `KlickyProbe_AB_mount_v2_holder.stl` | Klicky (same folder) | 1 | Black | 1.6 | 0.10 |
| `Mount_magnet_holder.stl` | Klicky (same folder) | 1 | Black | 2.3 | 0.14 |
| `Mount_magnet_pressfit_helper.stl` | Klicky (same folder) | 1 | Black | 1.6 | 0.10 |
| `Mount_pressfit_holder_v2.stl` | Klicky (same folder) | 1 | Black | 6.6 | 0.42 |
| `Dock_mount_fixed_v2.stl` | Klicky (same folder) | 1 | Black | 22.7 | 1.36 |

- **Plate B06-P1** (12.1 h, 148 g): the Stealthburner + Clockwork 2 black parts *and* the whole Klicky set,
  19 objects. Merged 2026-09-06 from two plates to cut a swap.

Notes:
- **Hotend file choice is settled:** E3D Revo Voron → the `revo_voron` folder, `..._rear_cw2` for Clockwork 2
  ([SB printhead README](https://github.com/VoronDesign/Voron-Stealthburner/blob/main/STLs/Stealthburner/Printheads/README.md)).
- **Do not print an ADXL mount** — the Nitehawk-SB has one on board
  ([LDO Rev D guide](https://docs.ldomotors.com/en/voron/voron2/printed_part_guide_rev_d)).
- **Do not print the CW2 chain anchor** — the kit supplies "CW2 Chain Anchor Tilted" printed
  ([Rev D 350 BOM](https://docs.ldomotors.com/en/voron/voron2/350_BOM/Rev_D)).
- `cw2_captive_pcb_cover` is LDO's improved cable door (captive screw + external chamber thermistor); the stock
  alternative is `Clockwork2/cable_door_for_pcb.stl` if you'd rather.
- Klicky dock: **fixed** mount chosen for simplicity. If you later add the Decontaminator purge bucket, you need
  `Dock_sidemount_fixed_v2.stl` + `Dock_sidemount_left_v2.stl` instead (~25 g, 1.5 h).
- The `Probe_*_pressfit_helper` / `_holder` parts are jigs for pressing the 6×3 magnets in square. Print them —
  a crooked magnet is a probe that doesn't repeat.
  ([Klicky "What to print"](https://github.com/jlas1/Klicky-Probe/tree/main/Printers/Voron/v1.8_v2.4_Legacy_Trident))

---

### Batch B07 — Electronics bay + lighting · **2 plates · 16.0 h · 226 g black**
**Unlocks:** *Electronics* (p.148–173), *Controller* (p.174–179), *Wiring* (p.180–211).

| STL | Repo path | Qty | Colour | g ea | h ea |
|---|---|---:|---|---:|---:|
| `wago_221-415_mount_3by5.stl` | Voron-2 `STLs/Electronics_Bay/` | 1 | Black | 10.6 | 0.63 |
| `lrs_200_psu_bracket_x2.stl` | Voron-2 `STLs/Electronics_Bay/` | 2 | Black | 8.2 | 0.49 |
| `PSU_stabilizer_50mm.stl` | Voron-2 `STLs/Electronics_Bay/` | 1 **(verify)** | Black | 4.1 | 0.26 |
| `usb_adapter_mount.stl` | Nitehawk-SB `STLs/` | 1 file *(contains base **and** cover; kit supplies the base, so you get a spare; base only — cover body superseded by the V2 partial cover below)* | Black | 9.4 | 0.55 |
| `usb_adapter_mount_partial_cover.stl` | Nitehawk-SB-V2 `STLs/` | 1 | Black | 5.0 (est.) | 0.30 (est.) |
| `pcb_din_clip_x3.stl` | Voron-2 `STLs/Electronics_Bay/` | 3 *(one clip per file; spares — the kit supplies the 4 needed)* | Black | 5.9 | 0.35 |
| `handlebar_spacer_x4.stl` | LDOVoron2 `STLs/` | 4 | Black | 2.1 | 0.13 |
| `cob_light_strip_mount_100mm.stl` | LDOVoron2 `STLs/COB Light Strip/` | 6 | Black | 18.1 | 1.06 |
| `cob_light_strip_mount_50mm.stl` | LDOVoron2 `STLs/COB Light Strip/` | 2 | Black | 9.3 | 0.55 |
| `power_inlet_IECGS_1mm.stl` | Voron-2 `STLs/Skirts/` | 1 *(moved from B08 — consumed in Ch 09, p.156/167, not the skirts chapter; rides on B07-P1)* | Black | 36.2 | 2.11 |

- **Plate B07-P1** (7.9 h, 102 g): wago mount, PSU brackets ×2, PSU stabilizer, USB adapter mount, `usb_adapter_mount_partial_cover` (ground-lug mount, est.), DIN clips, handlebar spacers ×4, `power_inlet_IECGS_1mm`.
- **Plate B07-P2** (8.1 h, 124 g): the eight COB light-strip mounts, brimmed. Nothing else fits.

Notes:
- COB counts are LDO's own for a 2.4-350: **6× 100 mm + 2× 50 mm**
  ([COB README](https://github.com/MotorDynamicsLab/LDOVoron2/tree/main/STLs/COB%20Light%20Strip)).
  Each STL contains a 2-piece assembly joined with 2× M3 heat-sets + 2× M3×6 FHCS. This is the heaviest
  single group of "small" parts in the build — 127 g.
- `PSU_stabilizer_50mm` is marked **(verify)**: LDO Build Notes say *"PAGE 169 SKIP — the kit does not use a
  support bracket"*, which most likely refers to this part. It is 4 g; print it and only fit it if it's needed.
- **Do not print** `raspberrypi_bracket.stl`, `beefy_raspberry_bracket.stl` or `rs25_psu_bracket.stl` — Leviathan
  carries the Pi and there is no 5 V PSU in this kit
  ([Build Notes p.150, p.152](https://docs.ldomotors.com/voron/voron2/build-faq)).
- **Do not print** the Leviathan bracket set or the bed WAGO mount — both supplied printed.
- `power_inlet_IECGS_1mm` lives here, not in B08, because it's fitted in Ch 09 (p.156/167) — see `docs/manual/09-electronics-bay.md`.
- It cannot ride on **B07-P2**: with the mandated 3 mm brims the eight COB mounts plus the 118 × 66.8 mm inlet
  come to 46 280 mm², 84 % of the 250 × 220 bed, and no placement exists. It had a plate to itself until
  2026-09-06, when the outline packer proved it fits on **B07-P1** at a 6 mm gap, saving a swap.

---

### Batch B08 — Skirts and front modules · **4 plates · 29.2 h · 399 g black**
**Unlocks:** *Skirts* (p.212–239).

The skirt ring is made of ten structural segments plus two "module" pieces — the TFT mount and the power
inlet — that all share a 67–72 × 20 mm cross-section. On the 350 the ring works out as:
front = `front_skirt_a` + **TFT mount** + `front_skirt_b`; rear = `rear_center_skirt` + `power_inlet` + `keystone_panel`;
each side = `side_skirt_a` + `side_fan_support` + `side_skirt_b`.

| STL | Repo path | Qty | Colour | g ea | h ea |
|---|---|---:|---|---:|---:|
| `rear_center_skirt_350.stl` | Voron-2 `STLs/Skirts/350/` | 1 | Black | 71.9 | 4.18 |
| `front_skirt_a_350.stl` | Voron-2 `STLs/Skirts/350/` | 1 | Black | 41.4 | 2.42 |
| `front_skirt_b_350.stl` | Voron-2 `STLs/Skirts/350/` | 1 | Black | 41.4 | 2.42 |
| `side_skirt_a_350_x2.stl` | Voron-2 `STLs/Skirts/350/` | 2 | Black | 36.9 | 2.16 |
| `side_skirt_b_350_x2.stl` | Voron-2 `STLs/Skirts/350/` | 2 | Black | 36.9 | 2.16 |
| `side_fan_support_x2.STL` | Voron-2 `STLs/Skirts/` | 2 | Black | 33.0 | 1.93 |
| `keystone_panel.stl` | Voron-2 `STLs/Skirts/` | 1 | Black | 38.6 | 2.26 |
| `mount.stl` (BTT Pi TFT4.3) | LDOVoronTrident `STLs/BTT Pi TFT4.3 Mount/` | 1 | Black | 30.1 | 1.80 |

- **B08-P1** (6.3 h, 99 g): `rear_center_skirt_350`, `side_fan_support` ×1
- **B08-P2** (8.4 h, 108 g): `front_skirt_a_350`, `front_skirt_b_350`, `side_skirt_a_350` ×1
- **B08-P3** (9.5 h, 122 g): `side_fan_support` ×1, `side_skirt_a_350` ×1, `side_skirt_b_350` ×1, `mount.stl`
- **B08-P4** (5.0 h, 70 g): `side_skirt_b_350` ×1, `keystone_panel`

Every one of these is 117–182 mm on its long axis and 67–72 mm deep. Packed on bounding boxes that meant two
per plate; packed on the real outlines (`slicer/nest.py`, 6 mm between silhouettes plus each part's brim) the
C-shaped segments interleave and the set fits on four plates instead of six — the 2026-09-06 consolidation.
`power_inlet_IECGS_1mm` is not here: it moved to B07 (Ch 09, not the skirts chapter).
**These are the parts people see.** They print on the current Gen 1 GT2 belts, in numeric order like every
other batch — the Gen 2 belt upgrade is deferred to the INDX rebuild this winter (§8).

Notes:
- `mount.stl` vs `mount_thick.stl`: `mount.stl` is 30 g / 44.8 mm tall; `mount_thick.stl` is 74 g / 67.8 mm and
  gives access to the screen's brightness buttons with a pointy tool. `mount.stl` is the recommendation —
  swap if you find you want the buttons **(judgment; LDO links the folder, not a specific file)**
  ([mount README](https://github.com/MotorDynamicsLab/LDOVoronTrident/tree/master/STLs/BTT%20Pi%20TFT4.3%20Mount)).
- **Do not print** `mini12864_case_front/rear`, `[a]_mini12864_case_hinge`, `[a]_mini12864_case_front_insert`,
  `[a]_btt_knob_light_shield` — the touchscreen mount replaces that whole front module
  ([LDO Rev D guide](https://docs.ldomotors.com/en/voron/voron2/printed_part_guide_rev_d)).
- Optional: `[a]_fan_grill_open_optional_x2` (more airflow, less filtering) instead of `[a]_fan_grill_a/b`;
  `ldo_bestagon_insert` (in B02) snaps into the skirt hexagons — print more copies if you like the look.

---

### Batch B09 — Panels, filtration, spool · **5 plates · 21.8 h · 297 g black**
**Unlocks:** *Panels* (p.240–259) and the Nevermore install.

| STL | Repo path | Qty | Colour | g ea | h ea |
|---|---|---:|---|---:|---:|
| `corner_panel_clip_4mm_x8.stl` | Voron-2 `STLs/Panel_Mounting/` | 8 | Black | 3.0 | 0.18 |
| `midspan_panel_clip_4mm_x7.stl` | Voron-2 `STLs/Panel_Mounting/` | 7 | Black | 2.0 | 0.12 |
| `corner_panel_clip_6mm_x8.stl` | Voron-2 `STLs/Panel_Mounting/` | 8 | Black | 4.5 | 0.27 |
| `midspan_panel_clip_6mm_x8.stl` | Voron-2 `STLs/Panel_Mounting/` | 8 | Black | 2.9 | 0.18 |
| `bottom_panel_clip_x4.stl` | Voron-2 `STLs/Panel_Mounting/` | 4 | Black | 3.2 | 0.19 |
| `bottom_panel_hinge_x2.stl` | Voron-2 `STLs/Panel_Mounting/` | 2 | Black | 4.3 | 0.26 |
| `z_belt_cover_a_x2.stl` | Voron-2 `STLs/Panel_Mounting/` | 2 | Black | 6.9 | 0.40 |
| `z_belt_cover_b_x2.stl` | Voron-2 `STLs/Panel_Mounting/` | 2 | Black | 6.9 | 0.40 |
| `exhaust_cover.stl` | LDOVoron2 `STLs/` | 1 | Black | 30.2 | 1.76 |
| `exhaust_filter_grill.stl` | Voron-2 `STLs/Exhaust_Filter/` | 1 | Black | 9.9 | 0.58 |
| `V2_Duo_Plenum.stl` | Nevermore\_Micro `V5_Duo/V2/` | 1 | Black | 50.2 | 2.93 |
| `V2_Duo_Plenum_LID.stl` | Nevermore\_Micro `V5_Duo/V2/` | 1 | Black | 12.3 | 0.71 |
| `Regular_Cartridge(contributed_by_Bucknova).3mf` | Nevermore\_Micro `V5_Duo/V2/` | 1 | Black | 43.0 | 2.51 |
| `Regular_Cartridge_Lid(contributed_by_Bucknova).3mf` | Nevermore\_Micro `V5_Duo/V2/` | 1 | Black | 8.4 | 0.49 |
| `spool_holder.stl` | Voron-2 `STLs/Spool_Management/` | 1 | Black | 16.6 | 0.98 |
| `bowden_retainer.stl` | Voron-2 `STLs/Spool_Management/` | 1 | Black | 5.6 | 0.33 |

- **B09-P1** (4.5 h, 63 g): `V2_Duo_Plenum`, `V2_Duo_Plenum_LID`, `Regular_Cartridge_Lid`
- **B09-P2** (4.9 h, 67 g): `Regular_Cartridge`, `exhaust_cover`
- **B09-P3** (3.9 h, 55 g): `exhaust_filter_grill`, `spool_holder`, `bowden_retainer`, `z_belt_cover_a` ×2, `z_belt_cover_b` ×2
- **B09-P4** (4.2 h, 56 g): `corner_panel_clip_4mm` ×8, `midspan_panel_clip_4mm` ×7, `bottom_panel_hinge` ×2, `bottom_panel_clip` ×4
- **B09-P5** (4.3 h, 56 g): `corner_panel_clip_6mm` ×8, `midspan_panel_clip_6mm` ×8

**Why both 4 mm and 6 mm panel clips.** The manual mounts back and top panels with **1 mm foam tape**
(3 mm panel + 1 mm tape = 4 mm) and side panels with **3 mm foam tape** (3 + 3 = 6 mm, *"to prevent the gantry
from rubbing on the panels"*). Counting the clips in the manual's own illustrations: back panel 4 corner + 3
midspan, top panel 4 corner + 4 midspan → exactly the `_4mm_x8` / `_4mm_x7` quantities; each side panel 4 corner
+ 4 midspan → exactly the `_6mm_x8` / `_6mm_x8` quantities. (Manual p.239–244; the `_x#` filename suffix is the
authoritative count.)
**This mapping is an inference** — neither Voron nor LDO states which clip goes on which panel. The arithmetic
lands exactly, so I'm confident, but snap one clip of each thickness onto an extrusion with a 3 mm panel offcut
and the right foam tape before you commit to printing all 31.

**Nevermore V5 Duo, exactly which files.** The Voron-2 plenum/lid are STLs; the **cartridge and its lid are
3MF files** in the same folder (PrusaSlicer imports them fine). Use the **Regular** cartridge, not XL — XL wants
carbon pellets and a faster/louder fan. 8× 6×3 mm magnets, 6× M3 heat-sets. The cartridge has a **built-in
support you push out**. ([Nevermore README](https://github.com/nevermore3d/Nevermore_Micro),
[LDO Nevermore guide](https://ldomotion.com/guides/nevermore-v5-duo---v24))

**Exhaust:** you are *not* building the Voron exhaust filter (76 g, 4.5 h saved). LDO: *"print this exhaust cover
with the stock exhaust grill to seal the back panel"* — that is `exhaust_cover.stl` (LDO) + `exhaust_filter_grill.stl`
(Voron). Skip `exhaust_filter_housing`, `[a]_exhaust_filter_mount_x2`, `[a]_filter_access_cover`, `[a]_exhaust_fan_grill`. They come back
only with the optional chamber exhaust fan (added 2026-10-03, Ch 14 Part H): an add-on print outside the plates,
made after Step 14.25 has checked the machine — 101 g, 7.1 h in two jobs, `slicer/addons/exhaust-voron2/`.

---

### Batch B10 — Clicky-Clack door · **1 plate · 5.7 h · 76 g black** (+ the blue `Handle` from B02)
**Unlocks:** front door install, replacing the stock two-door assembly entirely.

| STL | Repo path | Qty | Colour | g ea | h ea |
|---|---|---:|---|---:|---:|
| `Handle-Hinge_Bottom.stl` | whopping\_Voron\_mods `clickyclacky_door/STLs/` | 1 | Black | 17.1 | 1.03 |
| `Handle-Hinge_Top.stl` | whopping\_Voron\_mods `clickyclacky_door/STLs/` | 1 | Black | 17.1 | 1.03 |
| `Hinge-L-sleeve-2X.stl` | whopping\_Voron\_mods `clickyclacky_door/STLs/` | **2** | Black | 9.0 | 0.60 |
| `Hinge-L-solid-2X.stl` | whopping\_Voron\_mods `clickyclacky_door/STLs/` | **2** | Black | 9.2 | 0.61 |
| `Latch.stl` | whopping\_Voron\_mods `clickyclacky_door/STLs/` | 1 | Black | 8.4 | 0.57 |
| `Panel_Clip.stl` | whopping\_Voron\_mods `clickyclacky_door/STLs/` | 1 | Black | 0.9 | 0.06 |
| `Handle.stl` | *(printed in B02, blue)* | 1 | Blue | 33.7 | 2.03 |

**Plate B10-P1** — all six black parts. 5.7 h, 76 g.

Notes:
- The "2X" in the filenames means **print two copies**; each file contains one body. Cross-check against the
  mod's BOM: 6 split bushings and 4 M5×45 dowel pins = 2 door hinges + 2 handle hinges.
- Hinge on the right / handle on the left? Mirror the two `Hinge-L-*` parts in the slicer; handle and latch are
  symmetric. ([Clicky-Clack README](https://github.com/tanaes/whopping_Voron_mods/tree/main/clickyclacky_door))
- **Because you're fitting Clicky-Clack, do not print** `door_hinge_x6`, `handle_a_x2`, `handle_b_x2`, `latch_x2`
  (Voron), nor LDO's `LDO Door/` set. That also means you lose the LDO kit-number nameplate — if you want it,
  print `LDO Door/handle_b_nameplate.stl` and glue it somewhere else.
- **Resolved (survey, 2026-09-05):** the Clicky-Clack "Blue" option is the door's **aluminium frame** colour,
  matching the blue LDO frame — visible trim around the front opening, sitting with the blue accent parts and
  the black body.

---

### Batch B11 — Bay ducting (PETG V0, outside the ASA run) · **5 plates · 25.0 h · 348 g Jet Black PETG V0**
**Unlocks:** *Electronics* (p.148–173): Ch 09 fits two printed conduits in place of LDO's five PVC wire ducts;
Ch 10 fits the strip fin. Layout v3, adopted 2026-09-23 — design record
`review/2026-09-23-bay-mods/layout-v3/layout-v3.md`. Page: [`manual/print/B11-bay-ducting.md`](manual/print/B11-bay-ducting.md).

**Not in any run total above or below.** Prusament PETG V0 Jet Black on the textured sheet, sliced with
`slicer/bay-ducts-petg.ini` (3 perimeters, 4/4 solid, 20 % grid, no supports: ducts carry no load, so not
Voron spec). STLs: MyStoopidStuff's remix of RyanDam's Cable Management Duct (Printables 502306, GPL-3.0),
stock pieces fetched into `slicer/stl/bayducts/mss/502306/`, remixes for the Rev D+ bay committed in
`slicer/stl/bayducts/remix/`. The parts table with per-copy grams is on the batch page; per plate:

- **Plate B11-P1** (0.4 h, 4 g) — before kit, printed first and alone: `V3L_COUPON_22N_DUCT` + cover, the
  lid-snap test for the narrowed middle run.
- **Plate B11-P2** (6.9 h, 96 g) — before kit: DC front run (`CMD_V3_1H_154mm_DUCT` ×2 + covers) and the
  three 90° corners (`CMD_V3_1H_90DEG` ×2, `V2L_90DEG_MIRROR`, + covers).
- **Plate B11-P3** (4.6 h, 73 g) — before kit: the AC conduit (`V3L_WIRE_BOX_PORT` + plain lid,
  `V3L_90DEG_R15` ×2, `CMD_V3_1H_T_SHORT`, endcaps ×2, + covers), `V2L_STRIP_FIN`, and the DC S-jog
  (`CMD_Remix-V3_DUCT-2B_45deg` ×2 + lids).
- **Plate B11-P4** (6.3 h, 82 g) — after the kit-day measurements: the custom lengths, `V2L_58mm_DUCT` ×3,
  `V2L_130mm_DUCT`, `V2L_70mm_DUCT`, `V3L_10mm_DUCT` ×3, `V3L_34mm_DUCT_HOLE`, + covers.
- **Plate B11-P5** (6.8 h, 93 g) — after the kit-day measurements, **only if** the Leviathan-to-PSU gap is
  ≥ 25 mm and the coupon passed: `V3L_154N_DUCT` ×2 and `V3L_T_REG_N` ×2, + covers. Otherwise the fallback,
  stock `CMD_V3_1H_T_REG` + one `CMD_V3_1H_82mm_DUCT`, with LDO's PVC middle duct kept.

Notes:
- Before kit, 3 plates, 11.9 h, 173 g; after the kit-day measurements, 2 plates, 13.1 h, 175 g.
- Kit-day confirmation: the v3 route adds ~195 mm to the A motor lead and ~129 mm to B. Either way, P4 and
  P5 print on schedule; a short lead gets a longer replacement (4-pin JST-XH) rather than a drop to layout v1.
- All five arrangements are provisional (`nest.py`), GUI QC pending.
- Options, no plate: orange-ASA endcaps; MSS's WARNING lid (Printables 505838) waits for the INDX.

---

## 4. Totals, margin, spool changes

### 4.1 How these numbers were produced

Every plate hour and gram in this document is a **PrusaSlicer 2.9.6 estimate**, produced by actually slicing
the plate — not modelled. `slicer/build_plates.py` arranges each plate's real STLs on the 250 × 220 bed,
applies the per-object brims, writes `slicer/plates/<plate>.3mf`, slices it and reads
`; estimated printing time (normal mode)` and `; total filament used [g]` from the G-code footer.
`slicer/estimates.csv` lists every plate beside the figure it replaced.

The configuration is the one in [`manual/print/00-slicer-setup.md`](manual/print/00-slicer-setup.md): system
presets `0.20mm STRUCTURAL @COREONE 0.4` / `Prusament ASA @COREONE HF0.4` / `Prusa CORE One HF0.4 nozzle`,
plus every override in that document — 4 perimeters, 5 solid top and bottom, 40 % grid, forced 0.4 mm
extrusion width, shrinkage compensation zeroed, and the reduced speeds. Grams use the profile's own
1.07 g/cm³ ASA density.

**What replaced what.** The previous figures (134.3 h / 2248 g) came from a geometry-plus-throughput model:
wall-and-skin volume × 1.03 overhead, time = volume ÷ 4.5 mm³/s. Sliced, the build is **157.0 h / 2092 g** —
**+17 % time, −7 % filament**. Both errors have the same root: the model assumed a flat 4.5 mm³/s, but the
override table deliberately trades throughput for quality (perimeters 70 → 55 mm/s, external 50 → 35, first
layer 45 → 25), and it over-counted material by treating 4 perimeters as a solid 1.6 mm wall where Arachne
varies the beads. Every plate moved the same direction — the largest single change is B07-P1 at +2.2 h — so
the *shape* of the plan (which plates are long, which are short, what to start in the morning) is unchanged.

**Still calibrate on the first plate.** These are estimates from a slicer, not measurements from a printer.
Slicing `slicer/plates/B00-P1.3mf` yourself will return 3 h 58 m and 51.7 g to the minute, because it is the
same file. What is worth measuring is the *printer*: record B00-P1's wall-clock time and the weight of what
comes off the bed, and carry that ratio forward.

**Cross-check against the community numbers:** stripping the mods (the Klicky set ≈51 g, COB mounts 124 g, LDO extras)
gives ≈ **0.95 kg functional** and ≈ **0.90 kg cosmetic**, against the widely-quoted ~1.0 kg / ~0.9 kg for a
Voron 2.4 350 set. Total print time 157.0 h sits at the top of the commonly reported 120–160 h band — which is
what a quality-biased profile is supposed to do.

### 4.2 Filament budget

PrusaSlicer 2.9.6 estimates. The old model said 1940 g black / 308 g blue; slicing gives 127 g and 29 g
less — margin you gain, not a budget to spend.

| | Needed | On hand | Margin | Reprint allowance |
|---|---:|---:|---:|---:|
| **Galaxy Black** | **1813 g** | 2400 g (3 × 800 g) | **587 g** | **32 %** |
| **ASA Blue** | **279 g** | 800 g (1 × 800 g) | **521 g** | **187 %** |
| Total | 2092 g | 3200 g | 1108 g | — |

**Black margin is comfortable, but not unlimited.** 587 g is about three of the largest plates. Typical
first-build reprint rate is 10–15 %, so you should land fine — but:

- Don't burn black on the optional extras (`bed_hole_marking_template`, `bottom_panel_template`, purge-bucket
  sheet stops, extra bestagon inserts) until the machine is standing.
- If any single plate fails twice, order a fourth black spool that day rather than mid-B08.
- If you do run short, the cheapest place to substitute is the **skirts and panel clips** — those see no heat
  and no load, and the Voron docs explicitly permit PLA/PETG there
  ([materials page](https://docs.vorondesign.com/materials.html)). Don't substitute anywhere else.

### 4.3 Spool changes

Cumulative black consumed after each batch: B00 **52** · B01 **353** · B03 **472** · B04 **589** · B05 **667** ·
B06 **815** · B07 **1041** · B08 **1440** · B09 **1737** · B10 **1813 g**.

With 800 g spools and the numeric print order, spool **#1** carries B00 through **B05-P1** and ends with
~133 g. **B06-P1 starts spool #2** on that stub rather than risk a resume seam: the plate holds the Revo
hotend seat and the Clockwork 2 gear bores. #2 then runs to the end of **B08-P4** with ~27 g left, and
**spool #3 takes over mid-plate inside B09-P1** — Nevermore plenum, plenum lid and cartridge lid, nothing
dimension-critical, so the Core One+ runout sensor pausing and resuming there is fine. #3 finishes the build
with ~454 g spare. Same fresh-spool rule as B06 applies to B01-P1 (the 15.2 h, 201 g plate): a resume seam on
a Z-drive body is not worth the risk, so it wants ≥201 g on the spool at the start — it has 748 g. Record
what is *actually* consumed in the spool ledger in
[`manual/print/README.md`](manual/print/README.md#spool-ledger); the prediction above is only as good as the
first few weighings.

---

## 5. Orientation, brim, and per-batch checkpoints

### 5.1 Orientation and brim

**Do not change which face sits on the bed.** Every Voron, LDO, Klicky, Nevermore and Clicky-Clack STL ships
pre-oriented for support-free printing. Rotating a part **about Z** (in the plane of the bed) to make it fit is
fine — it does not change the layer orientation, and plate B08-P1 needs it (`side_fan_support` turned 90°).
Two exceptions to the face rule:

1. `XY_cable_chain_bridge-Igus-3mm_backer.stl` is a community remix and arrives standing 44 mm tall on a
   21 mm-wide footprint, unlike the stock part which lies flat. **Check it in the preview before slicing** — if
   it isn't sitting on a flat face, lay it down to match the stock `[a]_xy_joint_cable_bridge_2hole`.
2. Mirror the two Clicky-Clack `Hinge-L-*` parts if you want the door to swing the other way.

**No part in this build exceeds 150 mm in Z.** The tallest are, in order:

| Part | Height | Footprint | Aspect | Action |
|---|---:|---|---|---|
| `Handle.stl` (Clicky-Clack) | 60.0 mm | 67.9 × 18.6 | tall & narrow | **5 mm brim** |
| `Latch.stl` (Clicky-Clack) | 58.0 mm | 25.9 × 14.6 | very tall & narrow | **5 mm brim** |
| `Hinge-L-sleeve/solid-2X` ×4 | 55.0 mm | 20.9 × 19.5 | very tall & narrow | **5 mm brim** |
| `mount.stl` (TFT) | 44.8 mm | 117 × 67 | fine | none |
| `z_motor_mount_a/b` ×4 | 42.0 mm | 51 × 30.7 | borderline | brim if you see any lift |

Separately, **brim the long flat parts** — not because they're tall but because 150–182 mm of ASA on a plate lifts
at the ends: **3 mm brim** on `rear_center_skirt_350`, `front_skirt_a/b_350`, `side_skirt_a/b_350`,
`side_fan_support_x2`, `keystone_panel`, `power_inlet_IECGS_1mm`, `exhaust_cover`, `V2_Duo_Plenum`,
`Regular_Cartridge`, `wago_221-415_mount_3by5`, `exhaust_filter_grill`, `cob_light_strip_mount_100mm`.
Brim separation stays at PrusaSlicer's 0.1 mm so it snaps off.
([Prusa warping KB](https://help.prusa3d.com/article/warping_2011))

Parts with **built-in supports to break out, not cut**: `[a]_stealthburner_main_body`, `Regular_Cartridge`
(Nevermore), `V2_Duo_Plenum`. The skirts are single-shell parts — they have no break-away body.

### 5.2 Checkpoint after each batch

| After | Inspect | Most commonly reprinted here |
|---|---|---|
| **B00** | Gate A and Gate B in §1.4. Nothing proceeds until the rows you can run today pass; Gate B's bearing and rail rows sign off on kit day. | the cube, until the profile is right |
| **B01** | Each `z_drive_main` and `z_drive_retainer` 625-2RS pocket calipers **16.30 mm ±0.15** now; on kit day a real 625-2RS (16 mm OD) must thumb in with no rocking. M3 inserts wait for the kit's own (Step 02.04). Check the 4 mm/3 mm deck-support call. | `z_drive_main_*` — largest single parts, most exposed to warp at the corners |
| **B02** | Guidler and latch must move freely against the CW2 body once it exists (B06) — test-fit then, not now. Check the SB main body's built-in supports came out clean and the LED pockets are crisp. | `[a]_stealthburner_main_body` (most-photographed part in the build) |
| **B03** | The F695 flange seats caliper **15.00 mm** now; on kit day the real **F695-2RS** (13 mm OD, flanged) bearing/spacer stacks must drop into them without reaming. Either way the two halves of each drive unit must close flat with no gap. (625-2RS is the Z-drive bearing — B01, not this batch.) | `a/b_drive_frame_lower` — the bearing seats are the tightest fit in the machine |
| **B04** | Test the MGN12 carriage screw pattern against `x_frame_V2TR_MGN12_*` before you commit heat-sets. XY joint bores must accept the shafts without reaming. | `xy_joint_*_lower_MGN12` |
| **B05** | Z joints: `z_joint_lower`'s four M3 holes caliper 3.4 mm on a 15 × 16 mm pattern; `z_joint_upper` must sit square on the extrusion. | `z_joint_lower_x4` |
| **B06** | Revo Voron hotend must sit flat in the printhead front with 4× M3×8. Klicky: magnets pressed **below** the plastic surface, polarity consistent, and the probe must attach/detach cleanly from the AB mount. | `KlickyProbe_v2` (that's why you print two) |
| **B07** | Wago mount heat-sets; COB mount halves must close flush on their 2× M3×6 FHCS. | `cob_light_strip_mount_100mm` (warps at the ends — check flatness on glass) |
| **B08** | **Lay every skirt segment on a flat reference (your granite counter) and check for rocking.** A bowed skirt is the most visible defect on a finished Voron. Also dry-fit the ring: front + TFT mount + front, rear + inlet + keystone, sides + fan supports. | `rear_center_skirt_350` (182 mm — the worst warp candidate in the set) |
| **B09** | Panel clips: snap one onto an extrusion with a 3 mm offcut to confirm 4 mm vs 6 mm choice **before** printing all 31. Nevermore: plenum lid must slide in its groove; cartridge must snap onto the plenum. | the 6 mm corner clips, if the foam tape choice changes |
| **B10** | Sleeve bearings must tap into the hinge sleeves without splitting the part; M5×45 pin into the "solid" half should be a **very** tight hammer fit with ~20 mm proud. | `Hinge-L-solid-2X` (split risk on the pin press) |

Across the whole build, the three parts most often reprinted by Voron builders are the **A/B drive frames**
(bearing fit), the **long skirts** (warp), and the **Stealthburner main body** (cosmetics). Budget your 587 g of
black margin against those.

---

## 6. Conditional / verify items

| Item | Status | What to do |
|---|---|---|
| Deck support thickness | LDO's guide says 4 mm, LDO's **350** BOM says the deck panel is 3 mm | Print `deck_support_3mm_x8` ×8 now (the size-specific BOM wins); measure the panel on arrival; 8 g to reprint at 4 mm |
| `PSU_stabilizer_50mm` | LDO says "SKIP p.169 — no support bracket" | Print it (4 g), fit only if the PSU needs it |
| Probe retainer bracket | 8 mm vs 9 mm probe barrel | Measure the Omron on arrival; the `_9mm` variant is 0.5 g |
| Cable-chain bridge with Ti backers | Fabreeko's backers ship pre-drilled with **pilot** holes for the cable-chain end link (drill 2.5 mm, tap M3 to use them), which may make the printed bridge unnecessary; the backer-aware remix exists in 3 mm and 6.5 mm | Both the stock `[a]_xy_joint_cable_bridge_2hole` and `XY_cable_chain_bridge-Igus-3mm_backer` are on plate B02-P3 (18 g total). Fit whichever clears. "Igus" = the **2-hole** chain pattern, which is what LDO ships. |
| Keystone blanks | Panel has **2** slots; LDO supplies 1 CAT6 keystone | 1 blank used, 1 spare — both on B02-P3 |
| Clicky-Clack "Blue" | Fabreeko doesn't state what the colour governs | Ask before it ships |
| Rev D+ printed-parts guide | Doesn't exist; only Rev A/B, C, D | **Resolved:** D+ changes one printed part (§0). The remaining Discord question is only whether a D+ guide will be published. |
| `mount.stl` vs `mount_thick.stl` | LDO links the folder, not a file | `mount.stl` chosen (30 g vs 74 g); swap if you want brightness-button access |

**Optional, not in any batch** (print later if you want them): `bed_hole_marking_template_x1_Rev2` (LDO's bed is
pre-drilled), `bottom_panel_template`, `Purge Bucket/brush_holder_sheet_stop` + `individual_sheet_stop`
(superseded 2026-10-03: the nozzle scrubber is jinetix's silicone-wiper design with sheet stops,
[Printables 796563](https://www.printables.com/model/796563), an add-on outside the plates, **never printed ahead of kit day**: Ch 13 Part L
measures the machine, `slicer/addons/scrubber-796563/remix.py` generates the parts from those numbers (or says
no-go), and only then are they printed — about 3 parts, 38 g black ASA, 2 h 30 m; the kit's brass brush is a
hand tool),
`[a]_fan_grill_open_optional_x2`, `z_belt_cover_a_led` (LDO variant if you route the LED strip through the
Z-belt opening), extra `ldo_bestagon_insert`s.

---

## 7. Deliberately NOT printed

| File | Why |
|---|---|
| `nozzle_probe.stl` (Voron) and `nozzle_probe_ldo.stl` (LDO) | LDO supplies the nozzle probe printed |
| `Leviathan_bracket_set.stl` | Supplied printed (L + R) |
| `usb_adapter_mount` **base** body | Supplied printed (the file is still printed — for a spare **base**; the Nitehawk-SB V2 partial cover replaces its cover body) |
| `bed_wago_mount.stl` | Supplied printed |
| `led_fan_pcb_spacer_x2.stl` | Supplied printed (×2) |
| `[a]_pcb_spacer.stl` (CW2) | Supplied printed — printing a spare anyway, 0.3 g |
| `cw2_chain_anchor_tilted.stl` | Supplied printed |
| `[c]_stealthburner_LED_diffuser.stl` | Supplied printed in **clear PETG**; you have no clear filament |
| `[a]_endstop_pod_hall_effect.stl`, `z_joint_upper_hall_effect.stl` | No hall-effect endstops in this kit |
| `Octopus_bracket_set.stl` and all other `Controller_Mounts/*` | Leviathan, not Octopus |
| `raspberrypi_bracket.stl`, `beefy_raspberry_bracket.stl` | Leviathan has an integrated Pi mount (Rev D) |
| `rs25_psu_bracket.stl` | No 5 V PSU in this kit |
| `mini12864_case_front/rear`, `[a]_mini12864_case_hinge`, `[a]_mini12864_case_front_insert`, `[a]_btt_knob_light_shield` | BTT touchscreen replaces the mini12864 module |
| `exhaust_filter_housing`, `[a]_exhaust_filter_mount_x2`, `[a]_filter_access_cover`, `[a]_exhaust_fan_grill` | Nevermore replaces the stock exhaust filter; kit has no fan for it. Printed later only for the optional Ch 14 Part H exhaust fan, outside every batch |
| `door_hinge_x6`, `handle_a_x2`, `handle_b_x2`, `latch_x2`, LDO `LDO Door/*` | Clicky-Clack replaces the stock doors |
| `power_inlet_IECGS_1.2mm`, `power_inlet_filtered`, `plug_panel_1.2mm` | Kit ships the 1.0 mm inlet |
| `xy_joint_*_MGN9`, `x_carriage_*_MGN9`, `[a]_belt_clamp_MGN9_x2` (Superceded) | X axis is MGN12 |
| `zipchain2_*` (Superceded) | Kit ships real drag chain |
| `[a]_z_tensioner_x4_6mm` (Superceded) | Kit ships 9 mm-wide Z idlers |
| `pinda_adapter`, `chain_anchor_3hole*`, `cable_door.stl`, `Bowden/*`, `ADXL345_Mounts/*` | Wrong variant for this kit |
| `deck_support_4mm_x8`, `probe_retainer_bracket_9mm` | **Conditional, not excluded** — the caliper decides (§6). `deck_support_3mm_x8` is the printed default (Rev D 350 BOM); the 4 mm set is the reprint if the panel measures 4 mm. |
| `spool_holder`/`bowden_retainer` — *these ARE printed* (B09) | listed here only to avoid confusion with Spool_Management's other files |
| Beacon, Nevermore StealthMax, StealthChanger parts | Explicitly out of scope for this build |

---

## 8. Where to do the Core One+ Gen 2 belt upgrade

**Where things stand (2026-09-23).** The Core One+ is built and commissioned — commissioning closed
2026-09-13 on **Gen 1 (GT2) belts**, bed flat to ±0.1 mm on printed Z-stop correction caps. The
Gen 1 → Gen 2 upgrade kit (Prusa order 1787919456) has shipped. The LDO Voron kit has not: realistic
delivery is **late November to late December 2026**.

**Decision (2026-09-23): deferred to the INDX rebuild, this winter.** The Gen 2 upgrade is no longer done
before B00. It installs together with the INDX 8-tool conversion — Prusa documents the combined job
(<https://help.prusa3d.com/article/assemblling-the-prusa-indx-core-one-with-the-gen-2-upgrade_1147602>). The
whole 157.0 h / 22-plate run — B00 → B10, numeric order — prints on the current Gen 1 GT2 belts. This
supersedes the earlier "Gen 2 before B00" baseline and its 2026-10-15 contingency; the mid-run pause is
retired, because nothing changes the machine under the parts.

**Why.** The printer is commissioned and printing well; the upgrade fixes neither open issue on the bench
(loadcell/heater noise, PETG infill strands); a heatbed swap now risks the closed bed calibration and forces
a belt retune, XY-homing recal and a start-G-code re-sync of all 22 committed `.3mf` projects; GT1.5's only
benefit (less VFA) is cosmetic, and Galaxy Black's metallic fleck already hides it; one teardown, with INDX,
beats two.

**Two checks replace the upgrade, before B00** — full tick list at
[00-slicer-setup § Gen 2 belt upgrade](manual/print/00-slicer-setup.md#gen-2-belt-upgrade-deferred-to-the-indx-rebuild)
and [B00 § Before B00 checks](manual/print/B00-calibration-and-jigs.md#before-b00-belt-and-hot-bed-checks), both `(verify on bench)`:

1. **Belt pluck check** — belt tuning was never formally closed. Targets upper ≈96 Hz, lower ≈92 Hz, ≤8 Hz
   apart; out of range, retension via Control → Calibrations & Tests → Belt Tuning.
2. **Hot first-layer check, at ASA bed temperature** — the bed has only been verified flat at 60 °C. It runs
   after Step B00.0's wizard, on the committed project `slicer/checks/hot-first-layer.3mf`: five
   30×30×0.2 mm squares, corners + centre, one layer, in Galaxy Black ASA on B00-P1's presets (110 °C bed,
   cold start G-code); pass with no Z-alignment prompt, 0.17–0.23 mm each, spread ≤0.05 mm.

**Revised 2026-10-01: expansion joints and nozzle wiper before B00, belts at the INDX rebuild.** The
heatbed expansion joints and the nozzle wiper from the same kit are fitted before the two checks; the GT1.5
belts and pulleys still wait for INDX, so the run stays on GT2. The firmware switches for the joints and the
wiper are set one by one (Edition = Gen 2 would also set GT1.5 steps/mm), the bed is re-checked to ±0.1 mm
because the heatbed came off, and the hot check runs on both start G-codes (cold, and heat-then-off) to pick
the one all 22 plates carry. Tick list: [B00 § Before B00 checks](manual/print/B00-calibration-and-jigs.md#before-b00-belt-and-hot-bed-checks).

**After the eventual INDX + GT1.5 belt rebuild, before restarting prints:**

1. Firmware **≥ 6.8.1** (carries GT1.5 belt support and the Gen 2 expansion joints).
2. Re-tension both belts and re-square the gantry, per the combined INDX + Gen 2 guide.
3. Re-run the self-test and input shaper calibration.
4. **Re-print `Voron_Design_Cube_v7` and re-pass Gate A** (§1.4) — steps/mm changes with the pulleys, so the
   dimensional gate has to be re-passed before printing on the rebuilt machine. Judge its first layer per
   §1.4 step 3; the loadcell re-zeroes on its own and there is no wizard to redo.

Do **not** try to interleave a belt/tool upgrade with a running plate; the Nextruder and bed have to come apart.

---

## 9. Machine-readable batch summary

Hours and grams are **PrusaSlicer 2.9.6 estimates** sliced from `slicer/plates/*.3mf` (§4.1); per-plate
detail with the previous model figure beside each one is in `slicer/estimates.csv`.

`hard_prereq_batches` = batches that must be **printed** before the assembly chapter in `unlocks_chapter` can
actually be completed (B00 is the calibration gate for everything; B02 carries the accent parts that most
mechanical chapters need).

| batch_id | name | plates | hours | g_black | g_blue | unlocks_chapter | hard_prereq_batches |
|---|---|---:|---:|---:|---:|---|---|
| B00 | Calibration & jigs | 1 | 4.0 | 52 | 0 | Frame | — |
| B01 | Z drive assemblies | 2 | 22.8 | 301 | 0 | Z Drives and Idlers | B00;B02 |
| B02 | Accent parts (blue) | 3 | 21.9 | 0 | 279 | *(accent for Z Drives and Idlers, A/B Drives and Idlers, Gantry, Stealthburner, Skirts)* | B00 |
| B03 | A/B drive units + front idlers | 1 | 8.5 | 119 | 0 | A/B Drives and Idlers | B00;B02 |
| B04 | XY joints + X carriage | 1 | 8.6 | 117 | 0 | Gantry | B00;B02;B03 |
| B05 | Z joints + Z chain | 1 | 6.4 | 78 | 0 | Z Axis; A/B Belts | B00;B02;B04 |
| B06 | Toolhead (SB + CW2 + Klicky) | 1 | 12.1 | 148 | 0 | Stealthburner | B00;B02;B04 |
| B07 | Electronics bay + lighting | 2 | 16.0 | 226 | 0 | Electronics; Controller; Wiring | B00 |
| B08 | Skirts + front modules | 4 | 29.2 | 399 | 0 | Skirts | B00;B02;B07 |
| B09 | Panels, filtration, spool | 5 | 21.8 | 297 | 0 | Panels | B00;B08 |
| B10 | Clicky-Clack door | 1 | 5.7 | 76 | 0 | Panels (front door) | B00;B02;B09 |
| **TOTAL** | | **22** | **157.0** | **1813** | **279** | | |

```csv
batch_id,name,plates,hours,g_black,g_blue,unlocks_chapter,hard_prereq_batches
B00,Calibration & jigs,1,4.0,52,0,Frame,
B01,Z drive assemblies,2,22.8,301,0,Z Drives and Idlers,B00;B02
B02,Accent parts (blue),3,21.9,0,279,Multiple (accent),B00
B03,A/B drive units + front idlers,1,8.5,119,0,A/B Drives and Idlers,B00;B02
B04,XY joints + X carriage,1,8.6,117,0,Gantry,B00;B02;B03
B05,Z joints + Z chain,1,6.4,78,0,Z Axis;A/B Belts,B00;B02;B04
B06,Toolhead (SB + CW2 + Klicky),1,12.1,148,0,Stealthburner,B00;B02;B04
B07,Electronics bay + lighting,2,16.0,226,0,Electronics;Controller;Wiring,B00
B08,Skirts + front modules,4,29.2,398,0,Skirts,B00;B02;B07
B09,"Panels, filtration, spool",5,21.8,297,0,Panels,B00;B08
B10,Clicky-Clack door,1,5.7,76,0,Panels (front door),B00;B02;B09
TOTAL,,22,157.0,1813,279,,
```

Plate-level detail (batch, plate, hours, grams) for scheduling:

```csv
plate_id,batch_id,hours,grams,colour
B00-P1,B00,4.0,52,black
B01-P1,B01,15.2,201,black
B01-P2,B01,7.6,100,black
B02-P1,B02,7.0,90,blue
B02-P2,B02,7.3,93,blue
B02-P3,B02,7.6,96,blue
B03-P1,B03,8.5,119,black
B04-P1,B04,8.6,117,black
B05-P1,B05,6.4,78,black
B06-P1,B06,12.1,148,black
B07-P1,B07,7.9,102,black
B07-P2,B07,8.1,124,black
B08-P1,B08,6.3,99,black
B08-P2,B08,8.4,108,black
B08-P3,B08,9.5,122,black
B08-P4,B08,5.0,70,black
B09-P1,B09,4.5,63,black
B09-P2,B09,4.9,67,black
B09-P3,B09,3.9,55,black
B09-P4,B09,4.2,56,black
B09-P5,B09,4.3,56,black
B10-P1,B10,5.7,76,black
```

B11, the bay ducting, is outside the run and every total above. Its plates, by group
(`slicer/check_docs.py` checks this block):

```csv
plate_id,batch_id,group,hours,grams,colour
B11-P1,B11,before-kit,0.4,4,petg
B11-P2,B11,before-kit,6.9,96,petg
B11-P3,B11,before-kit,4.6,73,petg
B11-P4,B11,after-kit,6.3,82,petg
B11-P5,B11,after-kit,6.8,93,petg
TOTAL B11,B11,all,25.0,348,petg
```

---

## 10. Sources

**Voron official**
- Voron-2 repo, branch `Voron2.4` — <https://github.com/VoronDesign/Voron-2/tree/Voron2.4>
- Voron 2.4r2 Assembly Manual (2023-07-04) — <https://github.com/VoronDesign/Voron-2/blob/Voron2.4/Manual/Assembly_Manual_2.4r2.pdf>
  (print settings p.4; file naming p.5; deck panel p.28–30; skirts p.211–221; bottom panel p.232–233; Z belt covers p.234–236; panels p.239–244; exhaust p.250–256; spool holder p.257–259)
- Voron STL folder — <https://github.com/VoronDesign/Voron-2/tree/Voron2.4/STLs>
- Stealthburner repo — <https://github.com/VoronDesign/Voron-Stealthburner/tree/main/STLs>
- Stealthburner filename nomenclature — <https://github.com/VoronDesign/Voron-Stealthburner/blob/main/STLs/README.md>
- Stealthburner printhead compatibility — <https://github.com/VoronDesign/Voron-Stealthburner/blob/main/STLs/Stealthburner/Printheads/README.md>
- Stealthburner Assembly Manual — <https://github.com/VoronDesign/Voron-Stealthburner/blob/main/Manual/Assembly_Manual_SB.pdf>
- Voron materials selection (shrinkage = 100 %) — <https://docs.vorondesign.com/materials.html>
- Voron secondary printer tuning (belt tensions) — <https://docs.vorondesign.com/tuning/secondary_printer_tuning.html>

**LDO**
- LDO Voron 2.4 kit landing page — <https://docs.ldomotors.com/en/voron/voron2>
- Rev D printed parts guide — <https://docs.ldomotors.com/en/voron/voron2/printed_part_guide_rev_d>
- Rev D wiring guide — <https://docs.ldomotors.com/en/voron/voron2/wiring_guide_rev_d>
- Build Notes / FAQ (manual deviations by page) — <https://docs.ldomotors.com/voron/voron2/build-faq>
- Rev D 350 BOM — <https://docs.ldomotors.com/en/voron/voron2/350_BOM/Rev_D>
- LDO Nevermore V5 Duo assembly guide — <https://ldomotion.com/guides/nevermore-v5-duo---v24>
- LDOVoron2 STLs — <https://github.com/MotorDynamicsLab/LDOVoron2/tree/main/STLs>
- COB light strip mount counts — <https://github.com/MotorDynamicsLab/LDOVoron2/tree/main/STLs/COB%20Light%20Strip>
- BTT Pi TFT4.3 mount — <https://github.com/MotorDynamicsLab/LDOVoronTrident/tree/master/STLs/BTT%20Pi%20TFT4.3%20Mount>
- Nitehawk-SB STLs — <https://github.com/MotorDynamicsLab/Nitehawk-SB/tree/master/STLs>
- Nitehawk-SB V2 STLs (`usb_adapter_mount_partial_cover`) — <https://github.com/MotorDynamicsLab/Nitehawk-SB-V2/tree/master/STLs>
- Leviathan STLs — <https://github.com/MotorDynamicsLab/Leviathan/tree/master/STLs>

**Vendor**
- Fabreeko — LDO Voron 2.4 R2 (Rev D+) kit — <https://www.fabreeko.com/products/ldo-voron-v2-4-kit>
- Fabreeko — Clicky-Clack Door Kit by LDO — <https://www.fabreeko.com/products/clickyclackydoor-kit-by-ldo>
- Fabreeko — V2.4/Trident titanium extrusion backers — <https://www.fabreeko.com/products/v2-4-trident-titanium-extrusion-backers>

**Mods**
- Klicky Probe — <https://github.com/jlas1/Klicky-Probe> (what-to-print + BOM: <https://github.com/jlas1/Klicky-Probe/tree/main/Printers/Voron/v1.8_v2.4_Legacy_Trident>)
- Nevermore Micro (V5 Duo) — <https://github.com/nevermore3d/Nevermore_Micro>
- Clicky-Clack Fridge Door (whoppingpochard / tanaes) — <https://github.com/tanaes/whopping_Voron_mods/tree/main/clickyclacky_door>
- Extrusion backers — <https://github.com/tanaes/whopping_Voron_mods/tree/main/extrusion_backers>

**Prusa / slicer**
- PrusaSlicer releases (2.9.6 stable, 2026-06-25) — <https://github.com/prusa3d/PrusaSlicer/releases>
- PrusaResearch.ini @ version_2.9.6 (source of every quoted default) — <https://github.com/prusa3d/PrusaSlicer/blob/version_2.9.6/resources/profiles/PrusaResearch.ini>
- Prusa KB — ASA — <https://help.prusa3d.com/article/asa_1809>
- Prusa KB — Warping — <https://help.prusa3d.com/article/warping_2011>
- Prusa KB — CORE One to Gen 2 upgrade — <https://help.prusa3d.com/manual/prusa-core-one-to-gen-2-upgrade_2435>
- Prusa KB — CORE One downloads / firmware — <https://help.prusa3d.com/downloads/core-one>

**Community**
- Ellis' Print Tuning Guide — <https://ellis3dp.com/Print-Tuning-Guide/> (first-layer squish, extrusion multiplier, perimeter separation)
- Voron Print It Forward (the option not taken) — <https://pif.voron.dev/>

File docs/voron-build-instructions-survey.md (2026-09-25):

# Voron 2.4 R2 Rev D+ (LDO/Fabreeko, 350mm) — build-instruction source survey and consolidation spec

Compiled 2026-09-05. Every claim below was checked against the live source on that date; dates/versions are quoted from the source itself (HTTP metadata, PDF `ModDate`, wiki `updated-at`, GitHub commit dates), not from recall.

---

## 0. Verdict up front

- **Spine = the official Voron 2.4r2 Assembly Manual PDF** (263 pages, `ModDate` 2023-07-18), read *only* through **LDO's Build Notes/FAQ**, which is a page-indexed diff against that exact PDF commit.
- **Electronics/wiring/software spine = LDO Wiring Guide Rev D** (updated 2026-07-14), not the manual — the manual's Electronics/Controller/Wiring chapters (p.148–211) are almost entirely superseded.
- **"Rev D+" is a one-line hardware delta**: Rev D with the **Nitehawk-SB V2** toolboard. Everything else in the kit is Rev D. But that one delta invalidates a surprising amount of LDO's own Rev D toolhead text (MCU family, USB serial ID pattern, connector types, header keying, Klipper config file).
- **LDO publishes no Rev D+ document.** Verified by enumerating every link on `docs.ldomotors.com/en/voron/voron2`: guides exist for Rev A/B, Rev C, Rev D only. The Rev D+ specifics live in three other places (the `-sbv2` Klipper config, the Nitehawk-SB-V2 board doc, the Nitehawk-SB-V2 repo).
- **No video series exists for this kit revision at build-along granularity.** The only Rev D video content is a 4-part ~45-minute overview (123-3D, Oct–Nov 2024) and one 10-hour unedited livestream (Nathan Builds Robots, Feb 2025). Every step-by-step series is Rev A/B/C or a FormBot/Blurolls kit.

---

## 1. Kit facts (verified)

### 1.1 What "Rev D+" means

Fabreeko's product page for the exact SKU states, verbatim:

> **Rev D+ Changes for March 2026** — Nitehawk SB update with USB passthrough for USB based eddy current probes

— [fabreeko.com/products/ldo-voron-v2-4-kit](https://www.fabreeko.com/products/ldo-voron-v2-4-kit)

That is the *only* listed change vs. Rev D. Cross-checked against LDO's own board documentation, "USB passthrough" = the **Nitehawk-SB V2**:

> Added USB hub and secondary USB port as in Nitehawk-36 … Onboard microcontroller changed from RP2040 to **STM32G0B1** … Probe, TH0, XY Endstop ports changed from JST-XH2.5 to **JST-PH2.0** … Reversed connector gender between main toolboard and fan adapter PCB. The headers are also now keyed … Vastly Improved ESD performance.

— [docs.ldomotors.com/en/Toolboard/nitehawk-sb-v2](https://docs.ldomotors.com/en/Toolboard/nitehawk-sb-v2) (page created 2025-12-22, updated 2026-07-10) and [github.com/MotorDynamicsLab/Nitehawk-SB-V2](https://github.com/MotorDynamicsLab/Nitehawk-SB-V2) (README, repo pushed 2026-07-22)

Corroborating: LDO added `Firmware/leviathan-printer-rev-d-sbv2.cfg` to the kit repo on **2026-07-21** with the commit message *"feat(leviathan-rev-d): add Nitehawk-SB toolboard config"*, and its `Firmware/README.md` says *"This contains mainboard configs for LDO V2.4 kits Rev.D with the **Nitehawk-SB V2** toolboard."* — [github.com/MotorDynamicsLab/LDOVoron2](https://github.com/MotorDynamicsLab/LDOVoron2)

### 1.2 Rev D+ contents (electronics, probe, motion)

Sourced from the [Fabreeko SKU page](https://www.fabreeko.com/products/ldo-voron-v2-4-kit), the [LDO kit index](https://docs.ldomotors.com/en/voron/voron2), and the per-batch [LDO V2.4-350 Rev D BOM](https://docs.ldomotors.com/en/voron/voron2/350_BOM/Rev_D) (BOM page updated 2026-02-05).

| Subsystem | Rev D+ content | Note |
|---|---|---|
| Mainboard | **LDO Leviathan** (STM32F446 **(contested: F446 per wiring guide/config, H743 per LDO README since 2025-10-30 — read the silkscreen; see manual Ch 12 step 12.13)**), 5× TMC2209 + 2× TMC5160 HV for A/B, separate HV rail 24/48 V, on-board Pi mount + Pi HAT power adapter | Replaces BTT Octopus of Rev A–C |
| Toolboard | **Nitehawk-SB V2** (STM32G0B1, TMC2209, ADXL345, USB hub, secondary USB port, I²C port) + Fan Adapter PCB + USB Adapter PCB + flat umbilical | **The "+" in D+** |
| Toolhead | Stealthburner + **Clockwork 2**, Bondtech IGDA gear set, **E3D Revo HF** with 60 W heater (Rapido HF is a $9.99 swap) | ADXL mount not needed — accelerometer is on-board |
| Z probe | **Omron inductive probe** (QGL only) + fibreglass insulation tape. **Klicky Probe Kit** included as the optional alternative | **Not** Tap. **Not** Cartographer/Beacon. |
| Z endstop | LDO **nozzle probe** PCB (D2F microswitch + 5 mm shaft) + LDO printed part | Replaces the manual's `nozzle_probe.stl` and hall-effect endstops |
| XY endstop | LDO **XY microswitch PCB** (single 4-pin, breaks out to X Stop / Y Stop) | Manual's hall-effect pods not used |
| A/B motors | 2× `LDO-42STH48-2004MAH(VRN)` — **0.9°** (config uses `full_steps_per_rotation: 400`) | |
| Z motors | 4× `LDO-42STH48-2004AC(VRN)`, 1.8°, `gear_ratio: 80:16` | |
| Extruder motor | 1× `LDO-36STH20-1004AHG(VRN)` | |
| Rails | 1× `LDO-SLR12H-400Z1` stainless **MGN12H** (X); 6× `LDO-SLR9H-400Z0` stainless **MGN9H** (Y×2, Z×4). Ship **dry** | Grease before install |
| Bed | Cast 5083 Al, Blanchard-ground, 355×355×10 mm, LDO AC heatpad + 125 °C thermal fuse **pre-applied**, magnetic pad **NOT pre-applied** — separate BOM line `Magnetic Pad 2.4-350`, applied during the build (`docs/manual/03-build-plate.md`), spring-steel flex plate | Manual p.55/56 become no-ops (magnet still applied per manual) |
| Power | Meanwell **LRS-200-24** (US 110 V build; EU may get RSP-200-24), Omron SSR + DIN bracket, AC inlet with integrated switch + fuse | 115/230 V selector switch on the PSU |
| Screen | 4.3" capacitive DSI touchscreen + Pi ribbon cable | Mount STL lives in the **Trident** repo, not the V2 repo |
| Host | Raspberry Pi 4B + heatsink + 32 GB SD (BOM marks the Pi "OPTIONAL — check with your reseller"; the Fabreeko SKU includes it) | |
| Lighting | 2× **COB** LED strip + 2× splitter PCB (LDO ships the splitter spacers printed) | Rev D upgraded from discrete LEDs to COB |
| Filtration | **Nevermore Micro V5 Duo** parts, no carbon (shipping restriction) | Stock exhaust filter parts are optional and the fan is not included |
| Panels | Acrylic deck/back/bottom (black); PC clear doors/sides/top | See §4.3 — deck thickness is contested |
| Belts | Gates 2GT 9 mm × 6 m (Z), 2GT 6 mm × 6.21 m (A/B), 4× closed 2GT 6×188 mm loops (Z drive) | |
| Drag chain | 10×10 R18 × 2, 10×15 R28 × 1, **2-hole** chain ends | Print `*_2hole` parts, never `*_3hole` |
| Printed parts **included** by LDO | Leviathan Bracket L/R, NH Adapter Mount, DIN Clip ×4, CW2 Chain Anchor Tilted, 2×3 Splitter Spacer ×2, LDO Nozzle Probe, Bed WAGO Mount, Stealthburner LED Diffuser (clear PETG), CW2 PCB Spacer | Do **not** re-print these |

Bulk consumables that drive the build plan (Rev D 350 BOM): **153×** M3×5×4 brass heat-set inserts, **283×** M3×8 SHCS, 135× M3 roll-in T-nut, 80× M5 roll-in T-nut, 75× M3 hammerhead, 16× M5 hammerhead, 46× M5 1 mm precision spacer (used *instead of* every M5 shim in the manual), 44× M3×30, 43× M3×16-equivalent… plus 100 zip ties, 16× 6×3 mm magnets, VE0508 ferrules ×5, brass heat-set tip, 2 mm drill bit, 5 hex wrenches, 2.5 mm flat screwdriver, brass brush, 1 mm + 3 mm foam tape, 3M VHB.

**Batch-specific BOM.** LDO publishes a *separate BOM page per production batch*, indexed by kit serial (`V2-YYMM…`). The index at [350_BOM/HOME](https://docs.ldomotors.com/en/voron/voron2/350_BOM/HOME) (updated 2026-06-26) currently tops out at batch **2606**. Order F6424626 (2026-09-04, ETA **late November to late December 2026** — Fabreeko tracking page 2026-09-14: batch still in manufacture; watch for the status to flip to shipped, which starts a ~5-week clock) will be a later batch than 2606. **Action on arrival:** find the kit serial on the carton, open its batch BOM, and use *that* page as the inventory checklist — it has `Check1`/`Check2` columns designed for exactly this.

### 1.3 Documentation LDO actually publishes for this SKU

| Doc | URL | Created | Last updated | Images |
|---|---|---|---|---|
| Kit index / features | [docs.ldomotors.com/en/voron/voron2](https://docs.ldomotors.com/en/voron/voron2) | — | — | — |
| **Build Notes / FAQ** (page-indexed diff vs official manual) | [/voron/voron2/build-faq](https://docs.ldomotors.com/voron/voron2/build-faq) | 2022-09-12 | **2026-02-10** | few |
| **Wiring Guide Rev D** (incl. full software setup) | [/en/voron/voron2/wiring_guide_rev_d](https://docs.ldomotors.com/en/voron/voron2/wiring_guide_rev_d) | 2024-06-17 | **2026-07-14** | 39 |
| **Printed Parts Guide Rev D** | [/en/voron/voron2/printed_part_guide_rev_d](https://docs.ldomotors.com/en/voron/voron2/printed_part_guide_rev_d) | 2024-07-22 | 2025-07-14 | 20 |
| 350 BOM index (per batch) | [/en/voron/voron2/350_BOM/HOME](https://docs.ldomotors.com/en/voron/voron2/350_BOM/HOME) | 2022-06-22 | 2026-06-26 | — |
| 350 Rev D BOM | [/en/voron/voron2/350_BOM/Rev_D](https://docs.ldomotors.com/en/voron/voron2/350_BOM/Rev_D) | 2024-07-05 | 2026-02-05 | — |
| **Nitehawk-SB V2 board doc** (pinout, changes) | [/en/Toolboard/nitehawk-sb-v2](https://docs.ldomotors.com/en/Toolboard/nitehawk-sb-v2) | 2025-12-22 | 2026-07-10 | yes |
| Nitehawk-SB **V1** board doc (do not use for D+) | [/en/Toolboard/nitehawk-sb](https://docs.ldomotors.com/en/Toolboard/nitehawk-sb) | — | — | yes |
| Rail grease guide | [/guides/rail_grease_guide](https://docs.ldomotors.com/guides/rail_grease_guide) | 2022-01-31 | 2023-09-16 | 3 |
| Heat-set insert tool guide | [/guides/heatset_insert_tool_guide](https://docs.ldomotors.com/guides/heatset_insert_tool_guide) | 2021-05-19 | 2022-07-29 | 4 |
| Cable chain guide | [/guides/cable_chain_guide](https://docs.ldomotors.com/guides/cable_chain_guide) | 2021-09-25 | 2022-07-29 | 7 |
| **Leviathan V1.3 firmware guide** (numbered steps + step photos) | [ldomotion.com/guides/voron-leviathan-v1-3](https://ldomotion.com/guides/voron-leviathan-v1-3) | — | — | 30 |
| **Nevermore V5 Duo — V2.4** (numbered steps + step photos) | [ldomotion.com/guides/nevermore-v5-duo---v24](https://ldomotion.com/guides/nevermore-v5-duo---v24) | — | — | 37 |
| Klipper config (Rev D, Nitehawk V1) | [`Firmware/leviathan-printer-rev-d.cfg`](https://github.com/MotorDynamicsLab/LDOVoron2/blob/main/Firmware/leviathan-printer-rev-d.cfg) | — | 2026-07-21 | — |
| **Klipper config (Rev D+, Nitehawk V2)** | [`Firmware/leviathan-printer-rev-d-sbv2.cfg`](https://github.com/MotorDynamicsLab/LDOVoron2/blob/main/Firmware/leviathan-printer-rev-d-sbv2.cfg) | 2026-07-21 | 2026-07-21 | — |
| Hi-res Rev D wiring photos (GPL-3.0) | [`Images/WiringGuide/RevD/`](https://github.com/MotorDynamicsLab/LDOVoron2/tree/main/Images/WiringGuide/RevD) | — | — | 19 build + 6 UI |

Note: **ldomotion.com** (LDO's newer guide platform) hosts step-numbered, photo-per-step guides — literally the Prusa format ("Step 3 of 7 in this section", "Step Images"). Only two are relevant here (Leviathan, Nevermore); there is no Voron 2.4 *assembly* guide on it. This is the strongest existing evidence that the target format is achievable and that LDO would have done it if they had the budget.

---

## 2. Source survey

Legend for **Fit**: 🟢 use as-is · 🟡 use with documented overlay · 🔴 do not follow for this kit.

| # | Source | Covers | Kit rev / date | Format & strengths | Gaps / conflicts with Rev D+ | Fit |
|---|---|---|---|---|---|---|
| 1 | **Official Voron 2.4r2 Assembly Manual** — [`Voron-2/Manual/Assembly_Manual_2.4r2.pdf`](https://github.com/VoronDesign/Voron-2/blob/Voron2.4/Manual/Assembly_Manual_2.4r2.pdf) | Whole machine, Frame→Panels | Generic 2.4r2. Title page "VERSION 2023-07-04"; PDF `ModDate` **2023-07-18**; last commit touching `Manual/` 2023-07-18 ("stealthburner integration"). Release tag `V2.4r2` is 2022-02-23 | 263-page A4-landscape PDF, CAD exploded views, one action per page, fastener callouts drawn in place | No step numbers, no photos, no "what you should see" checks, no time estimates, no per-step BOM totals. Ch. Electronics/Controller/Wiring (p.148–211) is Octopus + 5 V PSU + mini12864 — **wrong board, wrong PSU topology, wrong screen** for this kit | 🟡 spine for mechanical (p.12–147); 🔴 for p.148–211 |
| 2 | **LDO Build Notes / FAQ** — [build-faq](https://docs.ldomotors.com/voron/voron2/build-faq) | Page-by-page deltas vs. #1 | Rev A→D. Page updated **2026-02-10**; explicitly pinned to manual commit `de7e89d`, "as of July 18, 2023" | Wiki text, ~35 numbered page callouts | Silent on everything Rev D+ (toolboard). Contains an internal contradiction on deck thickness (§4.3). Some notes still reference Rev A/C parts | 🟢 mandatory overlay on #1 |
| 3 | **LDO Wiring Guide Rev D** — [wiring_guide_rev_d](https://docs.ldomotors.com/en/voron/voron2/wiring_guide_rev_d) | Above-deck + below-deck wiring, mains, Checkpoint #1, Pi OS, KIAUH, KlipperScreen, firmware, USB IDs, printer.cfg | Rev D; updated **2026-07-14**; 39 images | The only end-to-end electrical doc for this machine. Has a real safety checkpoint with multimeter procedure. Sourced hi-res images on GitHub under GPL-3.0 | **Toolhead section is Nitehawk V1**: says JST-XH2.5 connectors, says the toolboard is RP2040, links the V1 `leviathan-printer-rev-d.cfg`. All three are wrong for Rev D+ | 🟢 spine for electrical, with §4.1 patch |
| 4 | **LDO Printed Parts Guide Rev D** — [printed_part_guide_rev_d](https://docs.ldomotors.com/en/voron/voron2/printed_part_guide_rev_d) | Which STLs to print/skip/substitute | Rev D; updated 2025-07-14; 20 images | Colour-coded (must / optional / already-in-kit). Names the 2-hole chain parts, D2F endstop pod, `power_inlet_IECGS_1mm`, 4 mm deck supports, COB light-bar clips | Points at the **V1** Nitehawk USB-adapter cover; V2 uses `usb_adapter_mount_partial_cover.stl` from the V2 repo | 🟢 with one substitution |
| 5 | **LDO Nitehawk-SB V2 doc + repo** — [board doc](https://docs.ldomotors.com/en/Toolboard/nitehawk-sb-v2) · [repo](https://github.com/MotorDynamicsLab/Nitehawk-SB-V2) | Pinout, connectors, change list, grounding images, `Configs/nitehawk-sbv2.cfg` | Rev D+ era; doc updated 2026-07-10, repo pushed 2026-07-22 | The authoritative Rev D+ delta. Full port/pin table. `ibom.html` interactive BOM, schematic PDF | Thin: no assembly text, no license file on the repo, grounding images (`grounding_scheme.jpg`, `toolboard_ground_routing.jpg`, `usb_adapter_gnd.jpg`) have **no prose anywhere** | 🟢 mandatory for Ch. toolhead + wiring |
| 6 | **Voron Stealthburner Assembly Manual** — [`Assembly_Manual_SB.pdf`](https://github.com/VoronDesign/Voron-Stealthburner/blob/main/Manual/Assembly_Manual_SB.pdf) | SB body, CW2 extruder, LEDs | 73 pages, "VERSION 2023-07-07", `ModDate` 2023-07-07; last `Manual/` commit 2023-07-13. High-contrast variant also present | Same CAD-exploded style; covers CW2 and the LED chain properly | Generic — assumes hartk 2-piece PCB, not Nitehawk V2. Fan/neopixel connector routing differs | 🟡 spine for Ch. toolhead with #3/#5 overlay |
| 7 | **Voron Documentation site** — [docs.vorondesign.com](https://docs.vorondesign.com) ([repo](https://github.com/VoronDesign/Voron-Documentation), pushed 2026-08-29) | Sourcing, **V2 gantry squaring**, software, **Initial Startup wizard**, tuning (belt tension, bed mesh), maintenance, community how-tos | Actively maintained; generic 2.4 | The Startup guide is a *stepped wizard with a progress bar* that branches on probe type and web UI — closest existing thing to the target format. Authoritative belt-tension numbers | Generic: nothing kit-specific. `build/electrical/v2_octopus_wiring.md` is the wrong board | 🟢 spine for Ch. squaring, startup, tuning |
| 8 | **Ellis' Print Tuning Guide** — [ellis3dp.com](https://ellis3dp.com/Print-Tuning-Guide/) · [repo](https://github.com/AndrewEllis93/Print-Tuning-Guide) (2.1k★, last push **2025-03-14**) | First-layer squish, pressure advance, extrusion multiplier, flow, max accel, VFA troubleshooting, macros | Printer-agnostic; also carries the original V2 gantry-squaring procedure | The de-facto community standard; LDO and Fabreeko both link it. Concrete, image-heavy, decision-tree structured | Not a build guide. Slicer examples are SuperSlicer-centric; needs translation to PrusaSlicer/Orca. No commits in ~18 months | 🟢 spine for Ch. tuning |
| 9 | **Klicky Probe** — [github.com/jlas1/Klicky-Probe](https://github.com/jlas1/Klicky-Probe) (1.4k★, pushed 2026-05-09) | Dockable microswitch probe, macros, `[gcode_macro]` set | Active | Only needed if he abandons the Omron. Kit ships the parts | Adds a whole macro layer and dock calibration; conflicts with the stock LDO config | 🔴 for the first build (defer) |
| 10 | **Nevermore Micro V5** — [github.com/nevermore3d/Nevermore_Micro](https://github.com/nevermore3d/Nevermore_Micro) (1.6k★, pushed 2025-01-01) + [LDO's V5-Duo–V2.4 guide](https://ldomotion.com/guides/nevermore-v5-duo---v24) | Filter build + mount | Current | LDO's version is **step-numbered with 37 step images** — already Prusa-format | Print the 3×6-magnet variant. Carbon media not supplied | 🟢 for Ch. filter/panels |
| 11 | **Extrusion backers + Clicky-Clack** — [github.com/tanaes/whopping_Voron_mods](https://github.com/tanaes/whopping_Voron_mods) | Ti backers; Clicky-Clack fridge door | Current, widely deployed | Backers README is explicit on **placement** (opposite the rail) and fasteners (M3×8 FHCS for Y, M3×6 FHCS for X, ~30 T-nuts; this build uses 29, one per backer hole, per Ch 05) | Clicky-Clack README has **no print settings and no install steps** — see #12 | 🟢 backers · 🟡 door |
| 12 | **KB3D wiki — LDO Clicky-Clacky Door Mod** — [wiki.kb-3d.com](https://wiki.kb-3d.com/en/home/LDO/LDO_Clicky_Clacky_Door_Mod) | Hinge/handle/latch assembly and mounting | Created 2024-10-27, updated **2025-09-15**; demonstrated on a 300 V2.4; **34 images** | The only photo-illustrated Clicky-Clack install guide. Lists the exact STL set and print settings | Reseller wiki (KB3D, not Fabreeko/LDO). Demo uses NanoNest panels, not the plain acrylic panel he ordered | 🟢 for Ch. door, with panel-mount substitution |
| 13 | **Voron community how-tos** — [`community/howto/simonthecat/I_wish_I_had_known.md`](https://github.com/VoronDesign/Voron-Documentation/blob/main/community/howto/simonthecat/I_wish_I_had_known.md) et al. | Accumulated first-build gotchas | Live in the docs repo | Genuinely non-obvious items: bed tacos from cold-tightening, 16T vs 20T Z pulleys look alike, never unplug a stepper with power on, don't hand-spin connected steppers | Unstructured, partly stale (Afterburner-era) | 🟢 mine for check-text, don't follow as a track |
| 14 | **Voron Discord** (`#voron_2_questions`, `#ldo_motors`) — [discord.gg/voron](https://discord.gg/voron) | Live Q&A, LDO's own support channel | Live | LDO's build-notes page explicitly directs Rev D corrections to `#ldo_motors`. Fastest path for a Rev D+ ambiguity | Not citable, not searchable offline, no version pinning | 🟢 as escalation only |
| 15 | **Fabreeko Discord** — [discord.gg/NV8Y6bcerP](https://discord.gg/NV8Y6bcerP) (linked from the SKU page) | Vendor support, missing/wrong parts | Live | Right channel for the *"is my batch Nitehawk V1 or V2"* question and for the XY-endstop-cable mis-label issue | Vendor-scoped | 🟢 as escalation only |
| 16 | **Voron forum** — [forum.vorondesign.com](https://forum.vorondesign.com) | Threads incl. the [Rev D launch thread (2024-06-12)](https://forum.vorondesign.com/threads/ldo-voron-rev-d-kits-are-now-live-at-fabreeko.1802/) | Live but Cloudflare-gated to scripted access | Useful archive of Rev D discussion | Thin traffic; no Rev D+ discussion found | 🟡 background only |
| 17 | **Steve Builds — "LDO Voron 2.4 Kit Hangout and Build"** ([playlist](https://www.youtube.com/playlist?list=PL0fUJbigELQPqpeGOgHYisG4KaSXVtnNY)) | 11 parts, full build | **Dec 2021 – Jan 2022 → Rev A/B** | Livestream video · Linked from LDO's own docs; Steve is on the Voron team | Octopus board, Afterburner toolhead, mini12864, 5 V PSU, discrete LEDs. **Nothing about the electronics half transfers** | 🔴 electrical · 🟡 mechanical only |
| 18 | **Nero3D / Canuck Creator — "Voron V2.4r2 LDOmotors kit Livestream build"** ([Part 1](https://www.youtube.com/watch?v=ZHO-kFlY91c), 3 h 49 m, 2022-02-15) | Full build, LDO kit | **Feb 2022 → Rev A/B** | Livestream · Nero is a Voron team member; the reference "why" commentary (t-nuts, rail grease NLGI 0/1, gantry racking) | Same revision problem as #17 | 🟡 mechanical rationale only |
| 19 | **Minimal 3DP — "Voron 2.4 R2 Build Guide"** ([playlist](https://www.youtube.com/playlist?list=PLXcVv43EZh9DzcPPF0IUVnpVdxQTQX8nE)) | 15 parts, Apr–Oct 2024, unboxing→wiring | **FormBot kit**, explicitly ("VORON 2.4 R2 Build Guide for the **FormBot** Kit") | Edited tutorial, 15–40 min/part · The best-structured recent mechanical series; chapter boundaries match the manual | Not the LDO kit. Different harness, board, bed, endstops. Rails/bed/probe differ | 🟡 mechanical only |
| 20 | **Build It Basement — "ULTIMATE Voron 2.4R2 Build"** ([playlist](https://www.youtube.com/playlist?list=PLjlotZjUVD32oT7YpPE89dqFwjCkVNKQ9)) | 15+ parts, Dec 2022 – Feb 2023 | 2.4r2, non-LDO; **includes Ti backers (Part 7.5) and Tap (Part 9.5)** | Edited tutorial · The only series with a dedicated **titanium-backers** episode and a gantry square-check episode (Part 8.5) | Uses Tap, not the LDO probe stack. Pre-Rev-D | 🟡 backers + gantry-square episodes only |
| 21 | **123-3D — "Building The Voron 2.4 Rev D LDO Motors Kit"** ([Part 1](https://www.youtube.com/watch?v=IushU1_ikKw) 2024-10-04 · [Part 2](https://www.youtube.com/watch?v=vpIDagUumgI) · [Part 3](https://www.youtube.com/watch?v=0cuV6iROV1k) · [Part 4](https://www.youtube.com/watch?v=QA0eMNXqI-E) 2024-11-08) | Unbox → frame/motion → electrics/gantry → first print | **Rev D**, Oct–Nov 2024 | 4 videos, ~10–15 min each (~45 min total) · **The only Rev D-specific series.** Shows the real Leviathan/Nitehawk bay layout | Far too coarse to build from — 45 minutes for a 50-hour build. Rev D, not D+ | 🟡 reference imagery only |
| 22 | **Nathan Builds Robots — "Help me build this printer! LDO Voron 2.4 Rev D Kit"** ([video](https://www.youtube.com/watch?v=hJPDsoD43dA), 2025-02-15, **10 h 13 m**) | One-sitting Rev D build | **Rev D**, Feb 2025 | Unedited livestream · Longest Rev D-specific footage in existence; good for "what does this actually look like" on the Leviathan bay | Unindexed, no chapters, real-time. Rev D, not D+ | 🟡 spot-reference (scrub to timestamp) |
| 23 | **Esoterical CAN-bus guide** — [canbus.esoterical.online](https://canbus.esoterical.online) / [repo](https://github.com/Esoterical/voron_canbus) (pushed 2026-04-23) | CAN toolhead bring-up, Katapult flashing | Current | The community standard for CAN builds | **Not applicable.** Nitehawk-SB V2 is USB; the kit ships no CAN hardware. Following it would add complexity for zero benefit | 🔴 |
| 24 | **voronldo.com "Voron Belt Tension Guide"** — [voronldo.com/guides/voron-belt-tension](https://voronldo.com/guides/voron-belt-tension/) | Belt tension numbers | "Last updated May 2025"; self-described *"independent resource site. Not affiliated with the Voron project"* | — | Publishes 350 mm targets (X 80–100 Hz, Y 75–90 Hz) that **contradict the official 110 Hz**, cites nothing, and is internally inconsistent (says Z "same as X/Y" then gives 110–130 Hz). Domain-for-sale notice on the page. Reads as SEO content | 🔴 **do not use** |
| 25 | **voron.dozuki.com** | Old wiki, step-format guides | Last revision **2019-12-09**; Voron 1.6/2.2/Afterburner | Dozuki step format | Format is right, content is 6 years obsolete | 🔴 |
| 26 | **CNC Kitchen — "Should you build a VORON 2.4 in 2023? (LDO Kit Review)"** ([video](https://youtu.be/nik-HCeOSB8), 2022-09-24) + [blog](https://www.cnckitchen.com/blog/building-a-voron-24-r2-in-2022-ldo-kit) | Review / expectation-setting | Rev A/B era | 23 min | Good expectation-setting for a first-timer; not instructional | 🟡 morale only |

---

## 3. Verdict — the single track and the per-phase overlay map

### 3.1 The spine

**Primary spine: the official Voron 2.4r2 manual PDF, pages 12–147, read through LDO's Build Notes.**
Reasons, in order of weight:

1. It is the only source that covers the whole mechanical machine at one action per illustration, with fastener callouts in place. Nothing else is even close on completeness.
2. LDO's Build Notes are a *page-indexed diff against that exact PDF*, pinned to commit `de7e89d`. That makes the two documents mechanically composable — every LDO deviation maps to a manual page number. No other kit vendor publishes this.
3. The PDF has not changed since 2023-07-18, so page numbers are stable and will stay stable. LDO's pinned link removes even that risk.
4. Everything else (videos, third-party guides) is either the wrong kit revision or the wrong vendor.

**Secondary spine: the LDO Wiring Guide Rev D, for everything from the electronics bay onward.** The manual's p.148–211 describe a machine this kit is not.

**Tertiary spine: docs.vorondesign.com Initial Startup wizard (V2 path) for bring-up, then Ellis for print tuning.**
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

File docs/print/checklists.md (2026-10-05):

# Printable checklists

_Generated by `scripts/build_printables.py` — do not hand-edit. Print with `.print-images` off (default) for a text-only sheet._

One page per checkpoint, assembly chapters first (Ch 00 → Ch 14, including Ch 00a and Ch 06b), then the print batches in print order (B00 → B10). **Gate A** and **Gate B** are the two halves of the B00 sheet — the day-1 and kit-day gates for the whole build.

## Checkpoint 00 — Before you start

- [ ] Both cartons inventoried against **your batch's** BOM page; `Check1` ticked on every line; shortages written down and reported to Fabreeko.
- [ ] Deck panel calipered on kit day; if it measures 4 mm, `deck_support_4mm_x8` reprinted (8 g, 30 min). B01-P2 printed the 3 mm set months earlier, on the BOM's word.
- [ ] Nitehawk board confirmed as a **V2**: PH2.0 on PROBE/TH0/CT/Endstop, XH on MOTOR, secondary USB port present, fan-adapter header keyed. The `stm32g0b1xx` USB-serial check is written into the Ch 12 notes.
- [ ] XY endstop cable labels read `XES / YES`, or the re-pin guide is bookmarked.
- [ ] Ten LDO-supplied printed parts binned and labelled "DO NOT PRINT". The V2 `usb_adapter_mount_partial_cover.stl` found in bin `08-CW2` (B07-P1); the spare V1 cover in `spare-alt`.
- [ ] Every fastener bag emptied into its labelled compartment in trays A–C, flattened and kept in the kit box; trays stacked.
- [ ] Every "Buy" row in Step 00.8 ordered or consciously skipped. Grease and IPA on the bench.
- [ ] Flat reference verified in five positions; worst feeler gap ≤ 0.1 mm and recorded; working area masked off and protected.
- [ ] Seven practice inserts set (one per coupon pocket): flush to ≤ 0.2 mm proud, square, boss not bulged > 0.2 mm. Working iron temperature written on the iron.
- [ ] All 7 rails: end stops taped 15 mm from each end, soaked 10 min in IPA ≥ 90% in their own bags, dried an hour or more, flip-and-packed until grease oozed at both end caps, rail surfaces wiped clean, labelled X / Y1 / Y2 / Z0–Z3, carriage taped, bagged with the end stops still on.
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

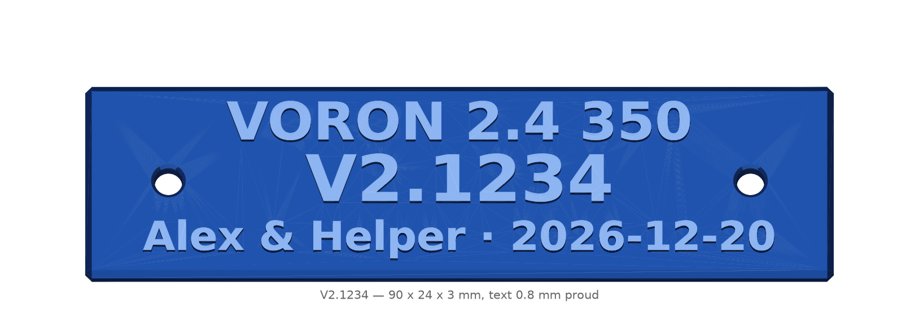
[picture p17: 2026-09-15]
docs/manual/assets/nameplate/nameplate.png

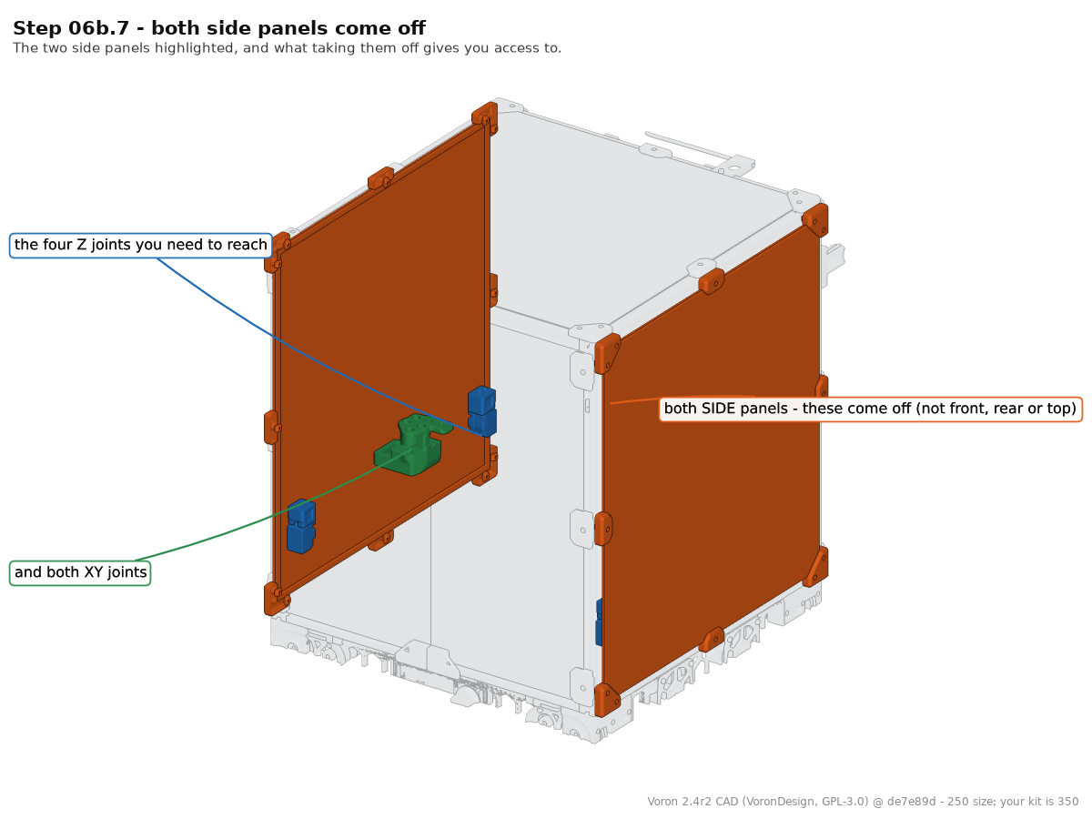
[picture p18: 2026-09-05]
docs/manual/assets/cad/06b-07-b.png

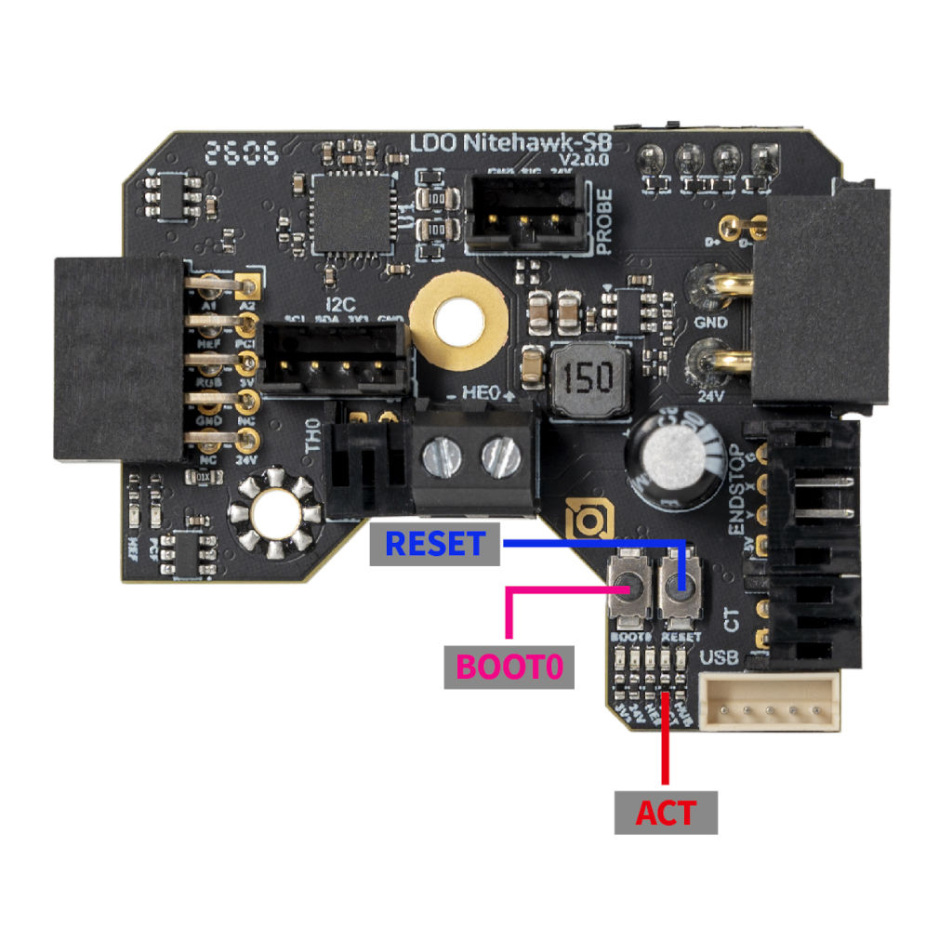
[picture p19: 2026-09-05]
docs/manual/assets/remote/12-software/nitehawk-sb-v2-reset-boot-buttons.jpg

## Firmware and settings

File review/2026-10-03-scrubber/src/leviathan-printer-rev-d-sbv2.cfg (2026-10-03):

# This file contains common pin mappings for the LDO Voron 2.4 Rev. D kit
# See docs/Config_Reference.md for a description of parameters.

## Voron Design VORON 2.4 250/300/350mm Leviathan V1.1 + Nitehawk-SB config

## *** THINGS TO CHANGE/CHECK: ***
## MCU paths                            [mcu] section
## Thermistor types                     [extruder] and [heater_bed] sections - See https://www.klipper3d.org/Config_Reference.html#common-thermistors for common thermistor types
## Z Endstop Switch location            [safe_z_home] section
## Homing end position                  [gcode_macro G32] section
## Z Endstop Switch  offset for Z0      [stepper_z] section
## Probe points                         [quad_gantry_level] section
## Min & Max gantry corner postions     [quad_gantry_level] section
## PID tune                             [extruder] and [heater_bed] sections
## Probe pin                            [probe] section
## Fine tune E steps                    [extruder] section

[mcu]
##  Obtain definition by "ls -l /dev/serial/by-id/" then unplug to verify
##--------------------------------------------------------------------
serial: /dev/serial/by-id/{REPLACE WITH YOUR SERIAL}
restart_method: command
##--------------------------------------------------------------------

[mcu nhk]
##  Obtain definition by "ls -l /dev/serial/by-id/" then unplug to verify
##--------------------------------------------------------------------
serial: /dev/serial/by-id/{REPLACE WITH YOUR SERIAL}
restart_method: command
##--------------------------------------------------------------------

[printer]
kinematics: corexy
max_velocity: 300  
max_accel: 10000
max_z_velocity: 15          #Max 15 for 12V TMC Drivers, can increase for 24V
max_z_accel: 350
square_corner_velocity: 5.0

#####################################################################
#   X/Y Stepper Settings
#####################################################################

##  B Stepper - Left
##  Connected to HV STEPPER 0
##  Endstop connected to X-ENDSTOP
[stepper_x]
step_pin: PB10
dir_pin: !PB11
enable_pin: !PG0
rotation_distance: 40
microsteps: 32
full_steps_per_rotation:400  #set to 200 for 1.8 degree stepper
endstop_pin: PC1
position_min: 0
##--------------------------------------------------------------------

##  Uncomment below for 250mm build
#position_endstop: 250
#position_max: 250

##  Uncomment for 300mm build
#position_endstop: 300
#position_max: 300

##  Uncomment for 350mm build
#position_endstop: 350
#position_max: 350

##--------------------------------------------------------------------
homing_speed: 25   #Max 100
homing_retract_dist: 5
homing_positive_dir: true

##  Make sure to update below for your relevant driver (2209 or 5160)
[tmc5160 stepper_x]
cs_pin: PE15
spi_bus: spi4
#diag0_pin: ^!PG1
interpolate: false
run_current: 0.8
sense_resistor: 0.075
stealthchop_threshold: 0

##  A Stepper - Right
##  Connected to HV STEPPER 1
##  Endstop connected to Y-ENDSTOP
[stepper_y]
step_pin: PF15
dir_pin: !PF14
enable_pin: !PE9
rotation_distance: 40
microsteps: 32
full_steps_per_rotation:400  #set to 200 for 1.8 degree stepper
endstop_pin: PC2
position_min: 0
##--------------------------------------------------------------------

##  Uncomment for 250mm build
#position_endstop: 250
#position_max: 250

##  Uncomment for 300mm build
#position_endstop: 300
#position_max: 300

##  Uncomment for 350mm build
#position_endstop: 350
#position_max: 350

##--------------------------------------------------------------------
homing_speed: 25  #Max 100
homing_retract_dist: 5
homing_positive_dir: true

##  Make sure to update below for your relevant driver (2209 or 5160)
[tmc5160 stepper_y]
cs_pin: PE11
spi_bus: spi4
#diag0_pin: ^!PE10
interpolate: false
run_current: 0.8
sense_resistor: 0.075
stealthchop_threshold: 0
 
#####################################################################
#   Z Stepper Settings
#####################################################################

## Z0 Stepper - Front Left
##  Connected to STEPPER 0
##  Endstop connected to Z-ENDSTOP
[stepper_z]
step_pin: PD4
dir_pin: !PD3
enable_pin: !PD7
rotation_distance: 40
gear_ratio: 80:16  
microsteps: 32
endstop_pin: PC3
##  Z-position of nozzle (in mm) to z-endstop trigger point relative to print surface (Z0)
##  (+) value = endstop above Z0, (-) value = endstop below
##  Increasing position_endstop brings nozzle closer to the bed
##  After you run Z_ENDSTOP_CALIBRATE, position_endstop will be stored at the very end of your config
position_endstop: -0.5
##--------------------------------------------------------------------

##  Uncomment below for 250mm build
#position_max: 230

##  Uncomment below for 300mm build
#position_max: 280

##  Uncomment below for 350mm build
#position_max: 330

##--------------------------------------------------------------------
position_min: -5
homing_speed: 8
second_homing_speed: 3
homing_retract_dist: 3

##  Make sure to update below for your relevant driver (2209 or 5160)
[tmc2209 stepper_z]
uart_pin: PD5
#diag_pin: ^!PD6
interpolate: false
run_current: 0.8
sense_resistor: 0.110
stealthchop_threshold: 0

##  Z1 Stepper - Rear Left
##  Connected to STEPPER 1
[stepper_z1]
step_pin: PC12
dir_pin: PC11
enable_pin: !PD2
rotation_distance: 40
gear_ratio: 80:16 
microsteps: 32

##  Make sure to update below for your relevant driver (2209 or 5160)
[tmc2209 stepper_z1]
uart_pin: PD0
#diag_pin: ^!PD1
interpolate: false
run_current: 0.8
sense_resistor: 0.110
stealthchop_threshold: 0

##  Z2 Stepper - Rear Right
##  Connected to STEPPER 2
[stepper_z2]
step_pin: PC9
dir_pin: !PC8
enable_pin: !PC10
rotation_distance: 40
gear_ratio: 80:16 
microsteps: 32

##  Make sure to update below for your relevant driver (2209 or 5160)
[tmc2209 stepper_z2]
uart_pin: PA8
#diag_pin: ^!PA15
interpolate: false
run_current: 0.8
sense_resistor: 0.110
stealthchop_threshold: 0

##  Z3 Stepper - Front Right
##  Connected to STEPPER 3
[stepper_z3]
step_pin: PG7
dir_pin: PG6
enable_pin: !PC7
rotation_distance: 40
gear_ratio: 80:16 
microsteps: 32

##  Make sure to update below for your relevant driver (2209 or 5160)
[tmc2209 stepper_z3]
uart_pin: PG8
#diag_pin: ^!PC6
interpolate: false
run_current: 0.8
sense_resistor: 0.110
stealthchop_threshold: 0

#####################################################################
#   Extruder
#####################################################################

##  Connected to STEPPER 0
##  Heater - HEATER
##  Thermistor - TH0
[extruder]
step_pin: nhk:PB8
dir_pin: nhk:PB9
enable_pin: !nhk:PC14
##  Update value below when you perform extruder calibration
##  If you ask for 100mm of filament, but in reality it is 98mm:
##  rotation_distance = <previous_rotation_distance> * <actual_extrude_distance> / 100
##  22.6789511 is a good starting point
rotation_distance: 22.6789511   #Bondtech 5mm Drive Gears
##  Update Gear Ratio depending on your Extruder Type
##  Use 50:10 for Stealthburner/Clockwork 2
##  Use 50:17 for Afterburner/Clockwork (BMG Gear Ratio)
##  Use 80:20 for M4, M3.1
gear_ratio: 50:10               #BMG Gear Ratio
microsteps: 32
full_steps_per_rotation: 200    #200 for 1.8 degree, 400 for 0.9 degree
nozzle_diameter: 0.400
filament_diameter: 1.75
heater_pin: nhk:PA7
## Check what thermistor type you have. See https://www.klipper3d.org/Config_Reference.html#common-thermistors for common thermistor types.
## Use "Generic 3950" for NTC 100k 3950 thermistors
sensor_type: ATC Semitec 104NT-4-R025H42G
sensor_pin: nhk:PB12
pullup_resistor: 2200
min_temp: 10
max_temp: 270
max_power: 1.0
min_extrude_temp: 170
control = pid
pid_kp = 26.213
pid_ki = 1.304
pid_kd = 131.721
##  Try to keep pressure_advance below 1.0
#pressure_advance: 0.05
##  Default is 0.040, leave stock
#pressure_advance_smooth_time: 0.040

##  E0 on MOTOR6
##  Connected to STEPPER 4
[tmc2209 extruder]
uart_pin: nhk:PB7
tx_pin: nhk:PB6
interpolate: false
run_current: 0.5
sense_resistor: 0.100
stealthchop_threshold: 0


#####################################################################
#   Bed Heater
#####################################################################

[heater_bed]
##  SSR Pin - HEATBED
##  Thermistor - TH1
heater_pin: PG11
sensor_type: ATC Semitec 104NT-4-R025H42G
sensor_pin: PA2
pullup_resistor: 2200
##  Adjust Max Power so your heater doesn't warp your bed. Rule of thumb is 0.4 watts / cm^2 .
max_power: 0.6
min_temp: 0
max_temp: 120
control: pid
pid_kp: 58.437
pid_ki: 2.347
pid_kd: 363.769

#####################################################################
#   Probe
#####################################################################

[probe]
##  Inductive Probe
##  Connected to Z-PROBE
##  This probe is not used for Z height, only Quad Gantry Leveling
pin: nhk:PC15
x_offset: 0
y_offset: 25.0
z_offset: 0
speed: 10.0
samples: 3
samples_result: median
sample_retract_dist: 3.0
samples_tolerance: 0.006
samples_tolerance_retries: 3
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

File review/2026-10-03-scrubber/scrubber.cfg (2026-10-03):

#####################################################################
#   Nozzle scrubber  — ADDED at Ch 13 (add-on). Geometry and macro logic
#   adapted from jinetix, "Voron 2.4 Silicone Nozzle Scrubber w/ Sheet
#   Stops", Printables 796563, macro revision 2025-12-22, CC BY-NC-SA 4.0.
#   Changes: one variable block instead of two copies; bucket on the LEFT
#   (mirrored fit); the circle radius and centre are clamped to this
#   machine's Y overtravel; XY moves happen at park height and Z drops only
#   over the bucket (the author's Z-then-XY order drags the nozzle at scrub
#   height); refuses to run until the values are measured.
#####################################################################

[gcode_arcs]
resolution: 0.1

[gcode_macro _SCRUB]
description: Scrubber geometry. Values only; read by NOZZLE_PARK_BUCKET and NOZZLE_CLEAN.
##  Every value marked (verify on bench) is measured on YOUR machine.
##  The placeholders below make both macros refuse to run.
variable_brush_x_min: -1.0     # (verify on bench) X, nozzle over the OUTBOARD (left) bristle edge
variable_brush_x_max: -1.0     # (verify on bench) X, nozzle over the INBOARD (right) bristle edge
variable_edge_y: -1.0          # (verify on bench) Y, nozzle tip exactly over the plate's rear edge
variable_z_scrub: 99.0         # (verify on bench) Z of the bristle tops minus 0.5
variable_bucket_offset: 10.0   # park this far outboard of brush_x_min, over the bucket
variable_park_z: 5.0
variable_circle_r: 2.0         # largest scrub circle; shrunk to fit the Y overtravel
variable_passes: 5
variable_circles: 2
variable_flicks: 5
variable_flick_depth: 3.0
variable_travel_speed: 9000
variable_flick_speed: 9000
variable_scrub_speed: 3000
variable_z_speed: 1500
gcode:
    {action_respond_info("_SCRUB only holds the scrubber's measured values")}

[gcode_macro NOZZLE_PARK_BUCKET]
description: Lift, then park the nozzle over the purge bucket.
gcode:
    {% set s = printer["gcode_macro _SCRUB"] %}
    {% if s.brush_x_min < 0 or s.brush_x_max <= s.brush_x_min or s.edge_y < 0 or s.z_scrub > 10 %}
      {action_raise_error("Scrubber not measured yet: fill in [gcode_macro _SCRUB]")}
    {% endif %}
    {% if printer.toolhead.homed_axes != "xyz" %}
      {action_raise_error("Scrubber: home all three axes first")}
    {% endif %}
    {% set ymax = printer.toolhead.axis_maximum.y - 0.5 %}
    {% set ylo = s.edge_y + 1.5 %}
    {% set r = [s.circle_r, (ymax - ylo) / 2.0]|min %}
    {% set cy = ylo + r %}
    G90
    G1 Z{[printer.toolhead.position.z, s.park_z]|max} F{s.z_speed}
    G1 X{s.brush_x_min - s.bucket_offset} Y{cy} F{s.travel_speed}
    G1 Z{s.park_z} F{s.z_speed}

[gcode_macro NOZZLE_CLEAN]
description: Flick ooze into the bucket, then scrub the nozzle on the silicone brush.
gcode:
    {% set s = printer["gcode_macro _SCRUB"] %}
    {% set ymax = printer.toolhead.axis_maximum.y - 0.5 %}
    {% set ylo = s.edge_y + 1.5 %}
    {% set r = [s.circle_r, (ymax - ylo) / 2.0]|min %}
    {% if r < 0.75 %}
      {action_raise_error("Scrubber: Y overtravel past the plate is too short for the brush")}
    {% endif %}
    {% set cy = ylo + r %}
    {% set bucket_x = s.brush_x_min - s.bucket_offset %}
    {% set flick_x = s.brush_x_min + s.flick_depth %}
    {% set x0 = s.brush_x_min + 0.5 %}
    {% set x1 = s.brush_x_max - 2 * r - 0.5 %}
    {% set dx = (x1 - x0) / (s.passes - 1) if s.passes > 1 else 0 %}
    NOZZLE_PARK_BUCKET
    G90
    G1 Z{s.z_scrub} F{s.z_speed}                ; down over the bucket, never over the brush
    {% for i in range(s.flicks) %}
      G1 X{flick_x} F{s.flick_speed}            ; into the outboard bristles
      G4 P20
      G1 X{bucket_x} F{s.flick_speed * 1.5}     ; snap back: the string drops in the bucket
    {% endfor %}
    {% for i in range(s.passes) %}
      {% set x = x0 + i * dx %}
      G1 X{x} Y{cy} F{s.travel_speed}
      {% for j in range(s.circles) %}
        {% if (i + j) % 2 == 1 %}
          G3 X{x} Y{cy} I{r} J0 F{s.scrub_speed}
        {% else %}
          G2 X{x} Y{cy} I{r} J0 F{s.scrub_speed}
        {% endif %}
      {% endfor %}
    {% endfor %}
    G1 Z{s.park_z} F{s.z_speed}                 ; lift straight up off the brush

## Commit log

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2026-09-06 WIP checkpoint: Fable fixes for Ch 02/03/06/07/08/09; DIN-rail deviation retracted; coupon insert count; video links follow swapped steps
    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
2026-09-06 WIP checkpoint: print/index/Tonight fixes (gate split, batch order), Ch 00 wording; strict build + lint green
    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
2026-09-06 Fable review fix wave: all F1–F9 findings applied (E-stop M112, gate split, squaring order, XY stack, Z-drive assembly, mains checkpoint, DIN-rail retraction, diagrams); re-read partial
    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
2026-09-06 Re-read G1 quick fixes (coupon count in 00.15, insert dims); G1 findings archived; remaining seams noted for next session
    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
2026-09-06 Re-read G7 fixes: no M84 with the gantry up (X/Y-only disable), PrusaSlicer temperature-emit warning in 13.41; G7 archived
    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
2026-09-06 Ch 02: interim notice on 02.32–02.33 (re-read G2 blocker); Z-drive diagram caption corrected; G2 archived
    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
2026-09-06 Diagram 04: cam pushes the motor away from the fixed drive body (re-read G2-G3)
    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
2026-09-06 WIP checkpoint: Ch 04 pulley-jig geometry (STL-measured), Ch 05 A-idler pairing and plane fixes, CAD label
    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
2026-09-06 WIP checkpoint: Ch 08/09 caption and landmark fixes from re-read G5; unreferenced mirror removed
    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
    [MANIFEST.csv, estimates.csv]
2026-09-06 CLAUDE.md: resume status — all chapter re-read fixes applied; bins in progress
    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
2026-09-06 Re-read G8 fixes: timeline diagram and printables generated from the index parser; slicer (modified) expectation; Tonight day-1 wizard segment; 25-bin scheme in Ch 00; check_docs section 6
    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
2026-09-06 Chapter progress renders: before/after CAD pair on every chapter overview
    One cumulative "state at the end of this chapter" render per assembly chapter
    (01-09, 11), from the same Voron 2.4r2 STEP cache the step illustrations use.
    `steps.yml` grows a `chapters:` list where each entry pins only what THAT
    chapter adds; `render_steps.py --chapters` unions the earlier ones for context,
    draws additions in the accent orange and everything earlier in neutral grey,
    and uses one fixed camera and frame box so the pairs line up as a sequence.
    --check-ids covers the new entries; re-running is byte-identical.
    build_steps.py shows the pair ("What this chapter builds") on the chapter
    overview and the after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
2026-09-06 Chapter renders: Ch 04 and Ch 05 end on the bench, and captions reach the page
    Both renders claimed an end state their own chapter denies. Ch 04: "All four
    assemblies are built on the bench and bagged; none of them touches the printer
    until Ch 05" - the render had them bolted to the frame. Checkpoint 05: "Gantry
    is upside down ... turned back at Ch 06 Step 06.11" - the render had it hanging
    in the machine, and the entry admitted as much in a `note_350` nothing read.
    A chapter entry can now name its own context (`context:`, a list of earlier
    chapters) and drop the fixed machine frame box (`frame: null`), so those two
    render the subassembly alone: Ch 04 the four assemblies, held in the positi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
2026-09-06 Ch 11 render: subtitle/caption no longer claim the Ch 10 chains are shown (they ride in grey, hidden by the panels)
    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
2026-09-13 CLAUDE.md: Core One+ commissioning closed 2026-09-13 (bed flat via correction caps, AFS attached with bypass flaps)
    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
2026-09-14 Plan revised for a Nov/Dec kit: whole print run before kit day, Gen 2 first, blue accent, cold start baked in, walkthrough fixes
    Physical-state sync (09-13): Core One+ commissioned on Gen 1 belts, Advanced Filtration fitted with bypass flaps, tools bought, firmware gate corrected 6.9.0 -> 6.8.1 (6.9.x is INDX-only).
    Plan (09-14): Fabreeko F6424626 realistically lands 2026-11-20..12-24, so all 22 plates print before the kit: Gen 2 belt upgrade -> B00 -> B01..B10 numeric; contingency pause demoted; KIT chapters follow with no plate waits; early Gate B without buying kit parts (KADRICK inserts + caliper checks against measured STL nominals); run-schedule table; Tonight planner reordered.
    Slic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
    [B00-P1.3mf, B01-P1.3mf, B01-P2.3mf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]
2026-09-14 Drift: re-pin PrusaSlicer-settings-prusa-fff at 46064d5 (bundle 2.5.9, 2026-09-08: INDX/XL filament profiles only; CORE One HF0.4 and Prusament ASA unchanged); slicer chapter notes 2.5.9
    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
2026-09-15 Interactive layer: gate calculators with why, Ch 14 tuning calculators, growing-printer Home, plate board, troubleshooting tap-tree, serial-number finale, helper track
    - gate-calc fences (hooks/gatecalc.py + gatecalc.js): YAML rows with band/limit/yes-no shapes, per-row why: disclosure, derive: for computed values; localStorage per gate. Authored on Gate A/B (B00.5, B00.7) and Ch 14 (belts, pressure advance with derived value, extrusion multiplier, squish, bed mesh).
    - Home shows the render of the highest fully ticked chapter and step progress (build-progress.json).
    - Plate board page: 22 plates with printed/sorted toggles, spool and slot from the ledger (plate-board.json; build fails on led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
    [nameplate.stl]
2026-09-15 Mascot: the raven, twenty poses in three views
    Generated by scripts/gen_mascot.py from one anatomy (profile, three-quarter, front), heron-level layered plumage with barbs, rachis lines and covert fringes, blue covert sheen, dark-mode halo, idle CSS animation gated by reduced-motion, per-side wing state with a two-wing tally guard. Poses: base (3 views), badge, check, tip, pass, fail, helper (adult + fledgling), warn, kitday, pause, print, gather, and six step actions (hexkey, caliper, point, carry, cable, screen). Review page docs/mascot.md under Reference; STYLE.md carries palette, construction, humour rule and the placement map. Name to be chosen later.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
2026-09-15 Mascot rollout: scenes, badges, panels across the manual
    hooks/mascot.py renders ```mascot fences (pose + caption ≤ 18 words; warn only in Ch 00a) as figures with page-relative paths; 32 scenes authored at every chapter, batch and plan head. Badges (check, tip, pause, gather, helper) in admonition titles via callouts/build_steps; pass/fail birds in the gate-calculator verdict; Home hero waves once, kit-day scene, print pose as the empty state; Tonight, plate board, bin labels and plate plans carry theirs; CSS classes mascot-badge/panel/scene/hero; CONVENTIONS documents the fence and the humour rule; glossary row.
    Claude-Session: htt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
2026-09-16 CLAUDE.md: AFS filtration line corrected — Adv. mode zeroes the chamber fans; M106 P3/P4 drive them from filament G-code (Buddy source verified 2026-09-15); M147 redundant for ASA
    Claude-Session: https://claude.ai/code/session_01F9uE5spGa6C7TwpahMs4m7
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2026-09-23 claude: bay ducting v2/v3 layouts (remixed MSS ducts for the LDO Rev D+ bay)
    - layout-v2: one DC loop with curved corners + one AC conduit; superseded.
    - layout-v3 (adopted by Alex 2026-09-23): printed middle run narrowed to 22 mm by
    slice-and-shift, MSS wire box at original size + re-radiused 90° curves for AC,
    no DIN-rail move (rail screws pass through fixed deck-panel holes), PSU 6 mm left.
    14 remix STLs, renders, scripts (BAY_MODS_SCRATCH points at the MSS downloads).
    - fit-report.md: rail-move claim corrected.
    MSS (Printables 502306/505838) and RyanDam's Cable Management Duct, GPL-3.0.
    Claude-Session: https://c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
    [V2L_130mm_DUCT.stl, V2L_130mm_DUCT_COVER.stl, V2L_22mm_DUCT.stl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]
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2026-09-23 claude: sweep fix work list (waves 1–5) for the next session
    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
2026-09-24 claude: sweep wave 2 — regressions, stale numbers, wayfinding
    - 10.80 fin between 3 FG and 4 −V (chapter numbering); layout-v3 lead
    images for 10.8–10.16 and 10.80 (leads_v3.py).
    - 09.6 dry-lays the DC conduit, VHB at 09.36; 09.16 from clearance
    targets; B11.8 = 26 pieces, B11.9 proxy check, B11.11 recipe fixed.
    - Heatset_Practice coupon = Gate B insert row only (B00.7); inserts 153.
    - Hot first-layer check after B00.0 with slicer/hot_check.py project.
    - Checkpoint Next buttons honour a **Next:** line (build_steps.py):
    06 → 07.1, 06b → 13.35, 10 → 12.11, B01 → B02.
    - HF0.4 presets in plan §1.3, Gate B table header, TESTZ removed,
    stale B07 pause, Tonight overlay claim,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
    [hot-first-layer.3mf]
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2026-09-24 claude: sweep wave 3 — remaining accuracy majors
    - Ch 01/02: Z-idler T-nuts in the top rail's inner slot; 01.16 M5×16
    tightened per the manual's sequence.
    - Ch 04/05: belt-offcut check, pulley planes, rail-hole rule, M3×16 count.
    - Ch 07: stop screws in the plain hole, Omron as a rectangular block,
    pre-terminated probe lead kept, belt-cut advice, tape once at 07.34;
    10.30 renamed to confirm the tape (old anchor kept).
    - Ch 09/11: probe lead above the deck, Leviathan brackets per p.155,
    11.52 DC lid visible, 11.37 cartridge fill.
    - Ch 14/15/16: SET_IDLE_TIMEOUT restores the timeout, MainsailOS numpy
    check, extrusion multiplier separated from shrinkage.
    - B11: P4/P5 gate only on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
2026-09-24 claude: wave 4 phase 1 — parts parser, crop tool, Tonight overlay, screenshots
    - scripts/parts.py owns Parts parsing (single-line and one-item-per-line),
    BOM lookup (scripts/data/ldo-350-bom.yml via kit_bom.py), grouped Gather;
    lint checks 6 (grammar) and 7 (Hardware reconciliation) in WARN mode.
    Generated step pages byte-identical.
    - scripts/crop_panels.py: deterministic manual-panel crops (--sheet/--render/--check).
    - Tonight overlay: build_tonight.py writes docs/assets/tonight.json, tonight.js
    re-plans 30/60/90 from this device's ticks; cross-row planner bug fixed;
    JS/Python parity in CI (check_tonight.mjs).
    - 18 screenshots (Klipper/Mainsail simulator, Raspberry Pi Imager; pl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
2026-09-24 claude: wave 4 phase 2 — crops, helper safety, checkpoint rewards, step Next
    - Crops: `{ crop="x0 y0 x1 y1" }` on a manual/SB page image renders the
    committed crop plus a Full page link; a declared, missing crop fails.
    - Helper lines in NO_MASCOT_STEPS fail the build; exception
    HELPER_RECORD_ONLY 10.74–10.78 (helper records, adult holds the probes).
    - Every Checkpoint renders a reward: Revali pass pose, the **Built:**
    line when present (WARN until phase 5), gummy worms (1 per 30 min of
    bench time; 1 per plate for batches); Checkpoint 00a text-only.
    - **Next:** override works on ordinary step pages; Next lines are exempt
    from the cross-reference budget.
    - 29 of 839 generated pag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
2026-09-24 claude: wave 4 phase 3 — one parts item per line; hardware ownership rule
    - Every assembly-chapter Parts line (Ch 00–14, 474 steps) converted to
    one item per line. Preservation check over 649 steps: ids unchanged,
    non-Parts text byte-identical, every (item, count) kept (four merged
    bullets in 08.5/08.7/08.43/10.62 split by hand).
    - Check 7 reconciles consumption, not listing: staged:/reused: roles,
    Ch 00 inventory excluded, cross-chapter owners and carries in
    scripts/data/hardware-ownership.yml; fake reuse and double counts fail.
    - `lint_manual.py --strict-parts --chapters NN,…` fails on checks 6/7 for
    just those chapters; default gate keeps them as WARN.
    - HARDWARE-OWNERSH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
    [hardware-ownership.yml]
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2026-09-24 claude: wave 4 phase 5 — integration: checks enforced, CONVENTIONS, leftovers
    - Checks 6 (Parts grammar) and 7 (hardware reconciliation) and the
    **Built:** requirement now FAIL the default lint for Ch 00–14.
    - NO_MASCOT_STEPS: 10.50 (iron), 08.34 (blade).
    - Gather: a staged item fitted in the same segment and a repeated tool
    are each listed once.
    - CONVENTIONS: Parts grammar and roles, ownership rule, strict mode,
    crops, Checkpoint reward and Built line, helper record-only exception,
    step-level Next.
    - 10-wiring: helper records readings, adult holds the probes;
    Checkpoint 13 Next → Ch 11 Part B (11.52); idler range 02.39–02.43.
    - WORKLIST: wave 4 ticked, leftovers listed.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
2026-09-24 claude: sweep wave 5 phase 1 — minor/polish findings, Ch 00–16 + Print tab
    Seven chapter packets (G1–G8 minor/polish rows) plus wave-4 leftovers:
    rail screws every other hole from the 2nd (9 per MGN9, 7 on MGN12; Ch 05
    T-nuts 29), Clicky-Clack hinge/handle-hinge screws corrected from the STLs,
    earth-check thresholds tightened to <1 Ω at the lug and plate screw,
    print/README "When the printer stops" + Ch 15 tap-tree branch, 10 glossary
    rows, nameplate = M3x8 SHCS (comments only). Gate green.
    Claude-Session: https://claude.ai/code/session_01WqzAPdcJW1PRJgg5HaHZHx
2026-09-24 claude: wave 5 — cross-file fixes deferred by the phase-1 packets
    00-index rail counts, 00a hand-over at 10.8 + earth thresholds, 00.16 insert
    pass timing (motor mounts have no inserts), Ch 15 runout on B09-P1, 12.11
    printer upright.
    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
2026-09-24 claude: sweep wave 5 phase 2 — render tooling, 09-ducts bin, plate board, CAD captions
    - Step pages render Do → Check → Helper → Parts (Alex 2026-09-24); "Tap to
    enlarge" under manual/crop figures; pre-kit tile badge; wide layout for
    long code blocks; long-chapter step headings excluded from search.
    - Home progress uses Tonight's planner: pre-kit next step, plates counted.
    - New bin 09-ducts for B11 (27 bins; check_docs now fails on stale counts);
    B11 sorting diagrams regenerated; fastener gauge on bin labels;
    checklist group spacing; plate board per-run headers, gate notes and
    four milestone badges.
    - Z-chain latch warning moved to 10.65 (LDO guide); 06.26 bag-and-label.
    -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
    [MANIFEST.csv]
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2026-09-24 claude: step pages back to Parts first — Gather → Parts → Do → Check → Helper
    Alex 2026-09-24: parts are prepared before they are assembled (Prusa order);
    reverses the same day's Check-after-Do render order (G2-26). CONVENTIONS and
    Home text follow.
    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
2026-09-25 claude: review bake-off 2026-09-24 fixes — 38 verified findings (M8 real; M9 rule clarified; M24/M27 not real)
    Fixed against page images, STLs and the CAD index, not reviewer text. Notable:
    - Index resynced to the chapters (sessions, hours, needs; 59.9 h, 146 sessions); diagram 11 regenerated.
    - 02.18 verifies the Z pulley with a caliper at 33 mm (pulley_jig only gauges the A/B pulleys).
    - 08.4 motor plate takes 7 inserts (Ch 08 total 18); 08.7 inserts go in sideways; 08.36 LED check per data wire.
    - 09.10/09.11 inlet panel: 3 inserts = 1 hinge + 2 belt guard; the IEC-GS module snaps in on its tabs, no screws.
    - 10.74/10.77 +V to PE expects about the +V to -V reading, not OL (GND-to-frame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
    [hardware-ownership.yml]
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2026-09-26 claude: kit-arrived planner — KIT build chapters are sequential; Home caption stops saying "nothing ticked"
    With KIT_ARRIVED = True, every kit-arrived plan offered Ch 10 wiring (10.1) when the next chapter's
    segment did not fit the bucket: KIT Build rows used the per-row rule. They are now sequential like print
    rows (Python planner, JS mirror, self-test + real-timeline check); the printer track still runs
    alongside, and the Before-the-kit plans are unchanged. Home: a ticked build with no chapter render yet
    (Ch 00 has none) no longer reads "Nothing ticked yet". Verified in a scratch kit-arrived build: 14/14
    JS/Python parity, Home progress + next-step links at empty/mid/after-Ch-01 states. T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
2026-09-26 claude: Home counts a plate as printed only when the plate board says so
    The plate board is the single authority for "printed" (Alex, 2026-09-26). A ticked Load step means
    started: it still moves Tonight's plan on, but Home no longer counts it as a plate off the bed, so Home
    and the board can't disagree (was 22/22 vs 0/22). Verified in a browser: Load steps ticked through B05
    with an empty board shows 0 of 22 on both; three plates marked on the board shows 3 of 22 on both.
    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
2026-09-26 claude: plate-board milestones full strength; crimp tool on the tools list; 2.9.6 for every batch
    - Printed tiles dim the thumbnail and body but no longer the milestone line (was opacity .62 on the whole tile).
    - Ch 00 tools table: ferrule crimp tool (VE0508), Buy, first needed Ch 09 (09.35 stages it).
    - Slicer chapter: 2.9.6 for every batch, B11 included (Alex, 2026-09-26); the 3.0 preview is reference only.
    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
2026-09-27 Revert "claude: AGENTS.md status — Voron plan paused 2026-09-26 (approved by Alex)"
    This reverts commit 8c74f7fbd4583a6c399a7dac107388962d1cb3f8.
2026-09-27 Revert "claude: AGENTS.md — Voron pre-order cancelled 2026-09-26, print run paused (approved by Alex)"
    This reverts commit 8f4b17281fa9ae12fe681da9482932ffa2d7974b.
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2026-10-03 Scrubber add-on: measure and decide before printing; pin Printables 796563
    Part L is now inspect → measure (H, w, d, G, O) → decide → print → fit
    (Steps 13.44–13.54, unpushed ids reworked). remix.py is the only
    generator: it derives the wiper-seat lowering and bucket trim from the
    measurements, or reports NO-GO and writes nothing. The committed STLs are
    its defaults only. The author's STEP is tracked unchanged with its hash.
    sources.yml pins the Printables page (file ids/sizes, macro-text hash);
    sources_verify.py checks it in every mode, including the weekly drift job.
    Claude-Session: https://claude.ai/code/session_01PVpRfPy5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
    [10mm Bed.stp, 350mm_bucket_trim2_MIRROR.stl, brush_bracket_L1.5_MIRROR.stl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]
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2026-10-03 claude: AGENTS.md — upstream re-check 2026-10-03, bundle 2.5.11; drift job covers Printables pins (approved by Alex)
    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
2026-10-03 Fix 13.41 export, 11.54 cover/grill + PTFE route, Nevermore only for filtered materials; Part H images
    13.41: Klipper flavour needs machine limits "time estimate only" (the 2.9.6
    CLI refuses otherwise) and binary G-code off (the Core One preset emits
    .bgcode); the Do is now a visible three-item list. 11.54: grill flange
    inside, LDO cover outside with 2 inserts, the kit's 4 mm bowden coupler,
    and M5 T-nuts/BHCS at 11.55; the PTFE route is written out (11.42, 11.55,
    and the coupler moves to the housing at 14.29). PRINT_START takes
    FILAMENT={filament_type}: the Nevermore runs only for ABS/ASA/HIPS/PC/PA/
    PP/FLEX, with a 10 min scrub after; filtered materials are never vented.
    Part H gets CAD re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
    [exhaust.cfg]
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2026-10-04 Bin labels: a picture beside every part
    Each "Should contain" item is a tile with a tight isometric render of the
    part (scripts/render_label_thumbs.py, render_parts.py's drawing without
    caption or scale bar; 160 PNGs incl. the add-on parts), its name, x qty and
    plate. Picture size steps with tile count: 20 mm (<=6), 15 mm (7-12),
    12 mm (13-18), 10 mm (19+). 09-ducts folds each matching cover/lid into
    its part's tile. Verified in the printed PDF: all 29 frames 200 x 130 mm
    with no overflow, every picture loads, gauge bar 50.0 mm.
    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
2026-10-04 Bag and box index replaces the bin map; 09-ducts in four plate-aligned B5 bags
    The printed index has one row per physical container (33): Filled and Used
    tick boxes, bag chip (A5 / B5 / BOX, readable in mono), part pictures,
    batches, first step and pieces, plus the containers outside the bin scheme.
    bins.containers() and BAG_SPLIT drive it; check_docs guards its counts.
    bin_bags.py --check now tests every bag of a split bin on its own: the
    first split (P1-P3 in one B5, 820 cm3 of 550) failed it, so 09-ducts is
    B5 x4, one per plate group (P1-P2, P3, P4, P5): 24/24 A5, 8/12 B5, 1 box.
    Claude-Session: https://claude.ai/code/session_01PVpR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
2026-10-05 Hardware trays as Gridfinity bins, fill-checked, no tools slot or lids
    gen_trays.py now builds each tray as a standard Gridfinity bin (42 mm
    pitch, 7 mm units, spec foot and stacking lip; matches Gridfinity Refined
    within 0.012 mm; magnet/screw holes optional, off by default). Each
    compartment is sized from part dimensions / packing fraction to <= 70 %
    fill (the generator fails above it). Each tray takes its own smallest
    size: A M2/M3 screws 5x5x6U, B M4/M5 screws 5x4x6U, C nuts, inserts,
    washers, spacers, magnets, T-nuts 5x4x6U; B and C stack. 24.5 h, 943 g
    PLA. Tools slot and lids dropped.
    Claude-Session: https://claude.ai/code/sessi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
    [lid-A.3mf, lid-A.stl, lid-B.3mf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]
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2026-10-13 Drift issue step, probe What-if rows, nozzle-probe pin position
    - drift.yml: set +e and PIPESTATUS[0]; under bash -e a CHANGED exit killed
    the step, so the issue step never ran.
    - Ch 13 What-if: probe too early = mounted too low, too late = too high or
    tape on the sensing face (causes were swapped).
    - Ch 09 / Step 09.30: the pin stands 1.5 mm behind the plate's straight rear
    edge (Voron manual p.161, LDO plate photo); there is no cut-out.
    Claude-Session: https://claude.ai/code/session_012mg7iShqQDzDWKCf7tDefM
2026-10-18 Commit B11's MSS duct STLs (Printables 502306 withdrawn); refresh source pins; firmware 7.0.0
    - slicer/stl/bayducts/mss/502306/: the 17 stock pieces, byte-for-byte as fetched 2026-09-23
    (GPL-3.0, credited in the bayducts README); the Printables API returns no print since
    2026-10-12. fetch_stls.py --verify: 168 files match MANIFEST.sha256.
    - sources_verify.py: a Printables pin marked `withdrawn: <date>` reports WITHDRAWN instead of
    failing the drift job, and CHANGED if the model comes back.
    - sources.yml re-verified: Klipper, LDOVoronTrident and PrusaSlicer-settings shas moved with no
    change to anything the manual uses (bundle 2.5.12 resolves our CORE One presets identically).
    - Docs: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
2026-10-19 AGENTS.md: split the status paragraph into manual and printing rules (approved by Alex; claude)
    Status, plate counts, kit timing and dated decisions move to PROJECT_MEMORY.md
    (local-only), regrouped into Printer / To print / Manual sections. Binding rules
    stay as bullets; authoring rules point to docs/manual/CONVENTIONS.md. 6809 -> 4241 bytes.
    Claude-Session: https://claude.ai/code/session_01Rw2nWQnbu1G1vEBe8LHnpQ
2026-10-21 B00 pre-checks: loadcell heater-noise test, firmware 7.0.0 and Live-Z checks
    New item 2: the loadcell test from the printer panel (Z 50, Sensor Info,
    cold / cable / 200 °C readings and what each decides). The hot check (now item 3)
    notes 7.0.0's automatic Z alignment and checks the shorter Absorbing-heat wait,
    the AFS blower and flaps, and whether Live Adjust Z is kept per sheet. Item 0:
    switch Expansion Joints on only once fitted. Section heading and anchor unchanged.
    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
2026-10-21 Pre-B00 checks are three: mirror the loadcell test in the plan, slicer setup and index
    The print plan and 00-slicer-setup list the loadcell heater-noise test as check 2;
    00-index's opening line and row 1 gate name all three. Calibration item 3 no longer
    claims Live Adjust Z is forgotten between prints: verify on bench, B00 item 3 settles it.
    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
2026-10-23 Add-ons review fixes: camera cable exits left, M3x20 body screws, three pegs, PTFE cut low
    Three STL-measured reviews of 82506c7e:
    - HappyCam: cable leaves the printer-LEFT end (pocket open at -x); body needs
    M3x20 (14.96 mm under the head); three locating pegs, new 11.68 gate row;
    3 m cable; plug in at 11.76; crowsnest keeps [crowsnest]; Z-max retest at
    position_max.
    - Side spool: tube holder on a hammerhead, ~22 cm back (clears the Drybox);
    PTFE cut with the gantry lowest; remix.scad feet stay solid for stack > 6.5
    (default STL byte-identical); stack limit 6.2.
    - Pins: sources_build.py keeps the three Printables pins; README credits the
    add-on sources; plan lists the add-ons an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

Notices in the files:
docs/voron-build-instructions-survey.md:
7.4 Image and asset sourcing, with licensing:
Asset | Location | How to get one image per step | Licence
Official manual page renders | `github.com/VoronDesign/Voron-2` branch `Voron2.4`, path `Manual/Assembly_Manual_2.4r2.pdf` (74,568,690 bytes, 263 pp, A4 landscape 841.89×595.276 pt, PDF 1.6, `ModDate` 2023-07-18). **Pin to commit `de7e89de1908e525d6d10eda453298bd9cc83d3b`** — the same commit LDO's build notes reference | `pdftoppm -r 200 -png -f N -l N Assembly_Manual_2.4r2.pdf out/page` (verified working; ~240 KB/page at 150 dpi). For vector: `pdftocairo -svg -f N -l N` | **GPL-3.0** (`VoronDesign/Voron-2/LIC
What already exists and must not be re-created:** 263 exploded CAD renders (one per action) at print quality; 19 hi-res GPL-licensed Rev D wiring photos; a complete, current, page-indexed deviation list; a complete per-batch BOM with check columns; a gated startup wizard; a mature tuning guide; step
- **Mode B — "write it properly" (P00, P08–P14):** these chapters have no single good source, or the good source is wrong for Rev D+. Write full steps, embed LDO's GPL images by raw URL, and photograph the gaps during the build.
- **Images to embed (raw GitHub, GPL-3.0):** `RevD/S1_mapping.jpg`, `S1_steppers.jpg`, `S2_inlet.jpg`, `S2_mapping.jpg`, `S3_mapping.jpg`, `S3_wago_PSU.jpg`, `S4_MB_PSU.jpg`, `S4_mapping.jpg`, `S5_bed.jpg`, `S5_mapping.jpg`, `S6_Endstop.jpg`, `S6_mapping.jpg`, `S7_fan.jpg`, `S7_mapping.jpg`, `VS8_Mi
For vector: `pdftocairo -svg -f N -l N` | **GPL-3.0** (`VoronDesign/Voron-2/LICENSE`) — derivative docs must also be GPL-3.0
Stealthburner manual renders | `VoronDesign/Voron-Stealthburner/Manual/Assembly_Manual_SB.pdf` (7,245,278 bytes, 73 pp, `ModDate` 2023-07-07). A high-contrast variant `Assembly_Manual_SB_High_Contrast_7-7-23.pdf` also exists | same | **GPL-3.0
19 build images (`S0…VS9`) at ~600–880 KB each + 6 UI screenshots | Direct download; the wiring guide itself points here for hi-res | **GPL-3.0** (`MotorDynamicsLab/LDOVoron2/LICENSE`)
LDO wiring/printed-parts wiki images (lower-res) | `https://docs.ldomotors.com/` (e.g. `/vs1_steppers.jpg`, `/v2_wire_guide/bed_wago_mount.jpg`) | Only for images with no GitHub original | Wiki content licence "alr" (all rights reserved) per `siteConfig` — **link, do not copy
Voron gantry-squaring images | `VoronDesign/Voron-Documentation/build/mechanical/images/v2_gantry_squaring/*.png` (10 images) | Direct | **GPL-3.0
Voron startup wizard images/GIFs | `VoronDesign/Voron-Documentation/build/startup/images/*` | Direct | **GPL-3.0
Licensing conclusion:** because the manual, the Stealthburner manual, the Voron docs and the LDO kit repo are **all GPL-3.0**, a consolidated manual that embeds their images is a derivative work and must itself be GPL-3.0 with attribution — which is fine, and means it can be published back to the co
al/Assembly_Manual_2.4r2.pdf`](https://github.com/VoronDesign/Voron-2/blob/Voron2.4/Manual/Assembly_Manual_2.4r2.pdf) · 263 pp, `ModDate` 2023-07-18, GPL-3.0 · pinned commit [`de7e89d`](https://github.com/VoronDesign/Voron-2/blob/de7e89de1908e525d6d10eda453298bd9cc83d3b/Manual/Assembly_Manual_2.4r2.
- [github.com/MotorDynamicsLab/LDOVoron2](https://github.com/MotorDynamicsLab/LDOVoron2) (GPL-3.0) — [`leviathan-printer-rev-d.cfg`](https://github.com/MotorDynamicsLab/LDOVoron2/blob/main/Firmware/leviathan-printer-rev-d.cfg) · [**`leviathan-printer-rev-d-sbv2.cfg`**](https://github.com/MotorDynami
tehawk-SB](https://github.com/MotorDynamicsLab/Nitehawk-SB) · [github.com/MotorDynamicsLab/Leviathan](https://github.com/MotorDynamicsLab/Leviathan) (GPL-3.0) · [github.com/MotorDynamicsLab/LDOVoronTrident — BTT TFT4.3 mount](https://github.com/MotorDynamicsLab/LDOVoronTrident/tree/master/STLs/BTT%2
